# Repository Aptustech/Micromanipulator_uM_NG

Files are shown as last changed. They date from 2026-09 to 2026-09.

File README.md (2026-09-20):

# Micromanipulator_uM_NG

> ⚠️ **Disclaimer:** This is a preliminary hardware design and is currently **untested**. Use or produce these designs at your own risk.

**Micromanipulator_uM_NG** is a next-generation controller system designed for precision micromanipulation. It improves upon previous designs by introducing higher processing power, expanded I/O capabilities, reliable high-speed sensor communication, and comprehensive power monitoring.

## Acknowledgments & Prior Work

This project is the next-generation iteration of the original electronic system for [MicroManipulatorStepper](https://github.com/0x23/MicroManipulatorStepper) by [@0x23](https://github.com/0x23).
---

## Interactive KiCAD Design Viewers

You can inspect the schematics and PCB layouts directly in your browser without opening KiCAD, powered by [KiCanvas](https://kicanvas.org/):

* 🔗 **[View Sensor Board (MT6835 V1.0)](https://kicanvas.org/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)**
* 🔗 **[View Controller Board (uM_Controller V1.0)](https://kicanvas.org/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)**

---

## Key Features & Highlights

* **Powered by RP2350B:** Upgraded to the RP2350B microcontroller to leverage its high IO count and advanced processing capabilities.
* **High-Speed LVDS Link:** Uses Low-Voltage Differential Signaling (LVDS) lines between the main controller and sensor boards, enabling a high-speed, noise-resilient SPI bus operating at **15 MHz**.
* **Power & Diagnostics:**
  * **Input Voltage Monitoring:** Real-time tracking of the main supply voltage.
  * **Per-Motor Current Sensing:** Dedicated current monitoring for each individual motor driver channel.
* **Modular Expansion:** Includes an dedicated extension connector for easily adding custom interfaces, daughterboards, or peripheral modules.

---

## Hardware Repository Structure

```text
├── MT6835/
│   └── V1.0/          # MT6835 encoder/sensor board design files
└── uM_Controller/
    └── V1.0/          # Main RP2350B controller board design files

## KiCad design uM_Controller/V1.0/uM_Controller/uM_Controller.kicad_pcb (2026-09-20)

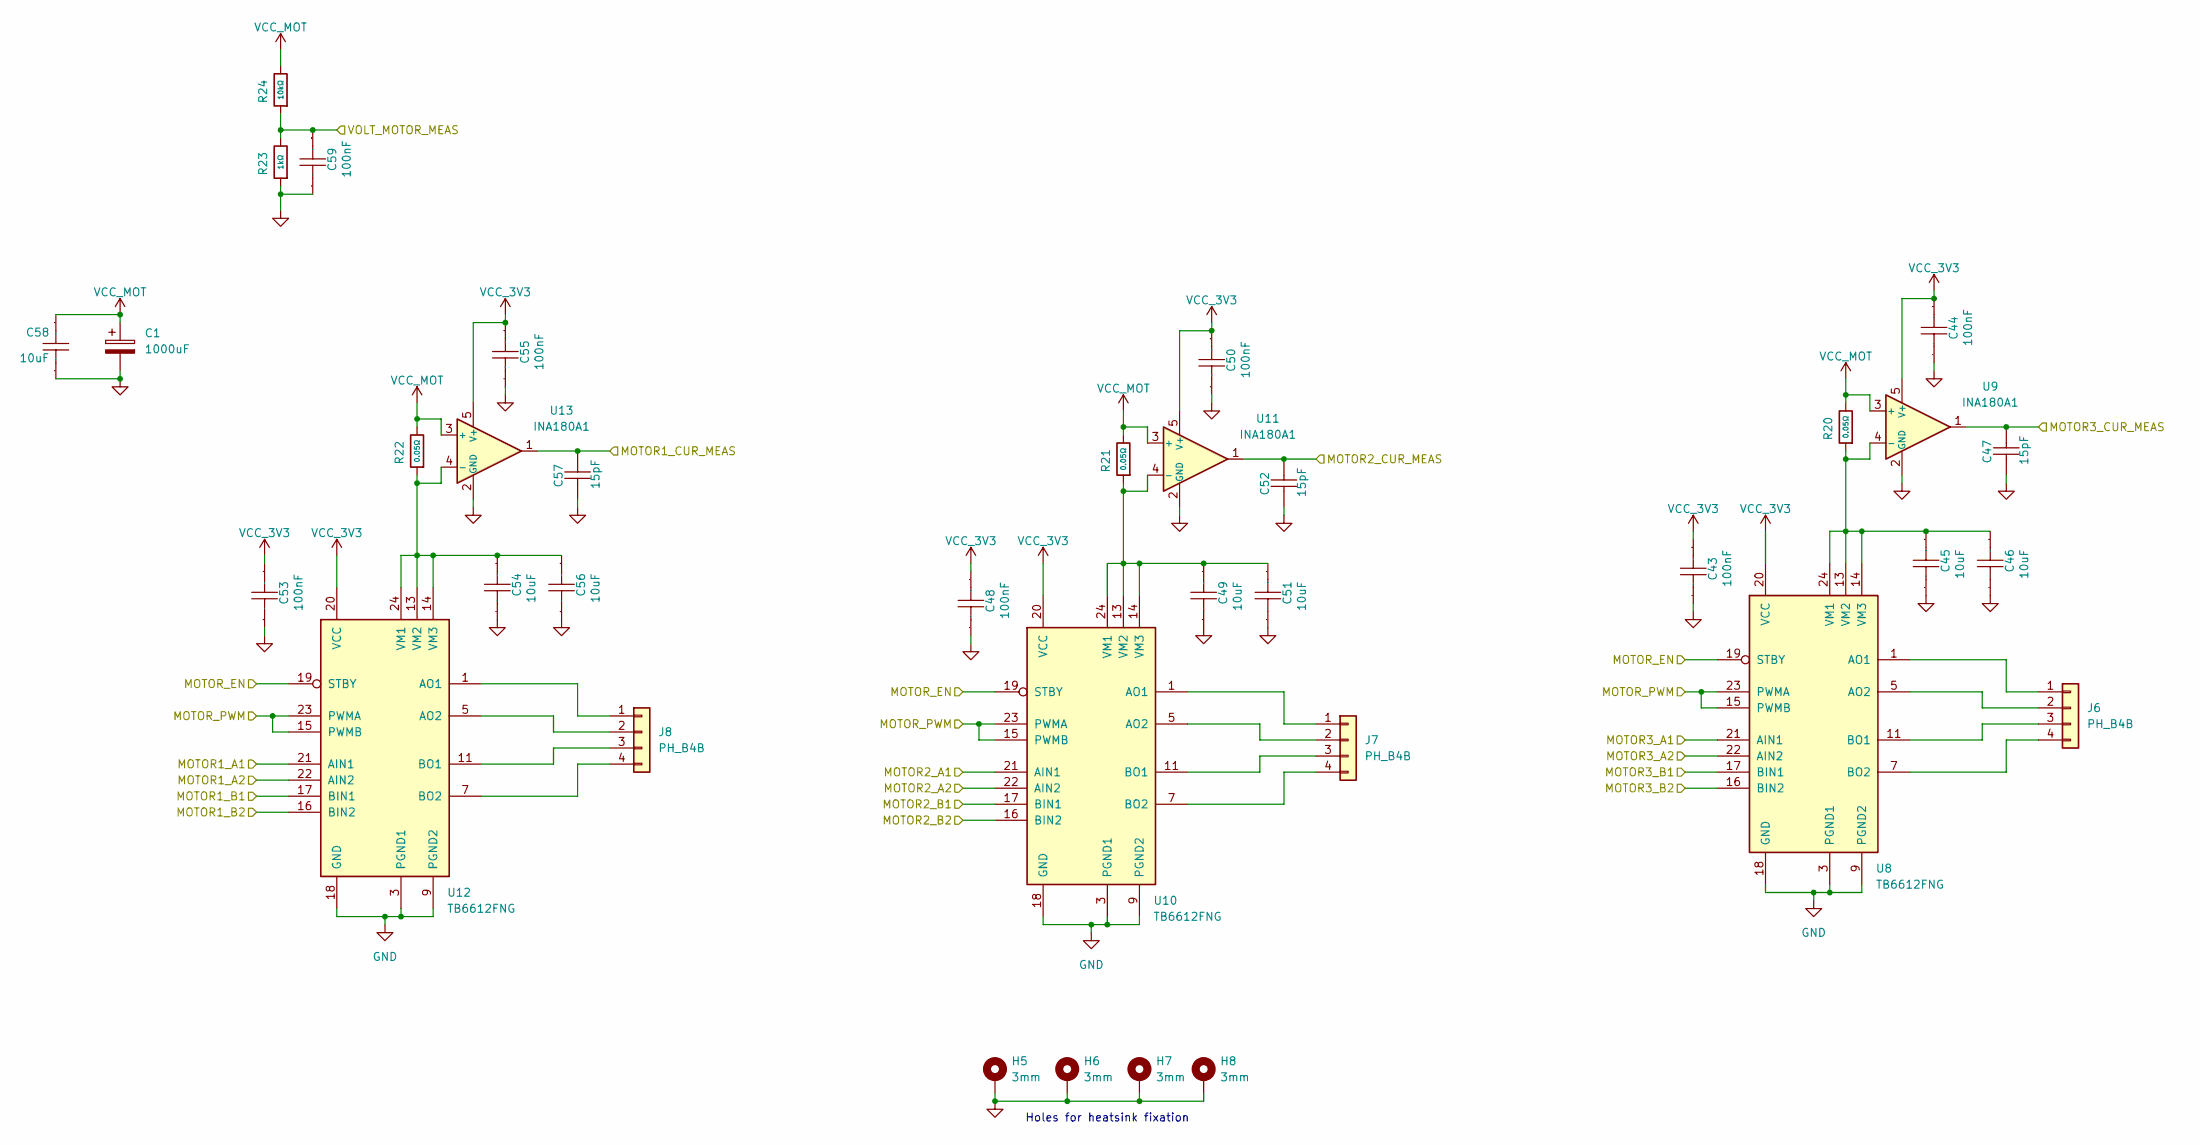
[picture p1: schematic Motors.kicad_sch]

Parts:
C1: 1000uF; CP_Radial_D10.0mm_P5.00mm_P7.50mm; Manufacturer Part 16ZLH1000MEFC10X16; LCSC C338175
C43, C44, C48, C50, C53, C55, C59: 100nF; C_0402_1005Metric; Manufacturer Part CL05B104KO5NNNC; LCSC Part Name 100nF ±10% 16V
C45, C46, C49, C51, C54, C56, C58: 10uF; C_1206_3216Metric; Manufacturer Part CL31A106KBHNNNE; LCSC Part Name 10uF ±10% 50V 1206
C47, C52, C57: 15pF; C_0402_1005Metric; Manufacturer Part 0402CG150J500NT; LCSC Part Name 15pF ±5% 50V
H5, H6, H7, H8: 3mm; MountingHole_3.2mm_M3_ISO14580_Pad_TopBottom
J6, J7, J8: PH_B4B; JST_PH_B4B-PH-K_1x04_P2.00mm_Vertical; Manufacturer Part PH-4A; LCSC C2321
R20, R21, R22: 0.05Ω; R_0805_2012Metric; Overload Voltage (Max) 50V; Tolerance ±1%; Part ERJ-6BWFR050V; LCSC C2075868
R23: 1kΩ; R_0402_1005Metric; Overload Voltage (Max) 50V; Tolerance ±1%; Part 0402WGF1001TCE; LCSC C11702
R24: 10kΩ; R_0402_1005Metric; Overload Voltage (Max) 50V; Tolerance ±1%; Part 0402WGF1002TCE; LCSC C25744
U8, U10, U12: TB6612FNG; SSOP-24_5.3x8.2mm_P0.65mm
U9, U11, U13: INA180A1; SOT-23-5

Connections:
/Motors/MOTOR1_A1: U12.21 (AIN1); also elsewhere on the board
/Motors/MOTOR1_A2: U12.22 (AIN2); also elsewhere on the board
/Motors/MOTOR1_B1: U12.17 (BIN1); also elsewhere on the board
/Motors/MOTOR1_B2: U12.16 (BIN2); also elsewhere on the board
/Motors/MOTOR1_CUR_MEAS: C57.1, U13.1; also elsewhere on the board
/Motors/MOTOR2_A1: U10.21 (AIN1); also elsewhere on the board
/Motors/MOTOR2_A2: U10.22 (AIN2); also elsewhere on the board
/Motors/MOTOR2_B1: U10.17 (BIN1); also elsewhere on the board
/Motors/MOTOR2_B2: U10.16 (BIN2); also elsewhere on the board
/Motors/MOTOR2_CUR_MEAS: C52.1, U11.1; also elsewhere on the board
/Motors/MOTOR3_A1: U8.21 (AIN1); also elsewhere on the board
/Motors/MOTOR3_A2: U8.22 (AIN2); also elsewhere on the board
/Motors/MOTOR3_B1: U8.17 (BIN1); also elsewhere on the board
/Motors/MOTOR3_B2: U8.16 (BIN2); also elsewhere on the board
/Motors/MOTOR3_CUR_MEAS: C47.1, U9.1; also elsewhere on the board
/Motors/MOTOR_EN: U8.19 (STBY), U10.19 (STBY), U12.19 (STBY); also elsewhere on the board
/Motors/MOTOR_PWM: U8.15 (PWMB), U8.23 (PWMA), U10.15 (PWMB), U10.23 (PWMA), U12.15 (PWMB), U12.23 (PWMA); also elsewhere on the board
/Motors/VOLT_MOTOR_MEAS: C59.1, R23.2, R24.1; also elsewhere on the board
GND: C1.2, C43.2, C44.2, C45.2, C46.2, C47.2, C48.2, C49.2, C50.2, C51.2, C52.2, C53.2, C54.2, C55.2, C56.2, C57.2, C58.2, C59.2, H5.1 (1_1), H6.1 (1_1), H7.1 (1_1), H8.1 (1_1), R23.1, U8.3 (PGND1), U8.4 (PGND1), U8.9 (PGND2), U8.10 (PGND2), U8.18 (GND), U9.2 (GND), U10.3 (PGND1), U10.4 (PGND1), U10.9 (PGND2), U10.10 (PGND2), U10.18 (GND), U11.2 (GND), U12.3 (PGND1), U12.4 (PGND1), U12.9 (PGND2), U12.10 (PGND2), U12.18 (GND), U13.2 (GND); also elsewhere on the board
unnamed: J6.1, U8.1 (AO1), U8.2 (AO1)
unnamed: J6.2, U8.5 (AO2), U8.6 (AO2)
unnamed: J6.3, U8.11 (BO1), U8.12 (BO1)
unnamed: J6.4, U8.7 (BO2), U8.8 (BO2)
unnamed: J7.1, U10.1 (AO1), U10.2 (AO1)
unnamed: J7.2, U10.5 (AO2), U10.6 (AO2)
unnamed: J7.3, U10.11 (BO1), U10.12 (BO1)
unnamed: J7.4, U10.7 (BO2), U10.8 (BO2)
unnamed: J8.1, U12.1 (AO1), U12.2 (AO1)
unnamed: J8.2, U12.5 (AO2), U12.6 (AO2)
unnamed: J8.3, U12.11 (BO1), U12.12 (BO1)
unnamed: J8.4, U12.7 (BO2), U12.8 (BO2)
unnamed: C45.1, C46.1, R20.1, U8.13 (VM2), U8.14 (VM3), U8.24 (VM1), U9.4 (-)
unnamed: C49.1, C51.1, R21.1, U10.13 (VM2), U10.14 (VM3), U10.24 (VM1), U11.4 (-)
unnamed: C54.1, C56.1, R22.1, U12.13 (VM2), U12.14 (VM3), U12.24 (VM1), U13.4 (-)
VCC_3V3: C43.1, C44.1, C48.1, C50.1, C53.1, C55.1, U8.20 (VCC), U9.5 (V+), U10.20 (VCC), U11.5 (V+), U12.20 (VCC), U13.5 (V+); also elsewhere on the board
VCC_MOT: C1.1, C58.1, R20.2, R21.2, R22.2, R24.2, U9.3 (+), U11.3 (+), U13.3 (+); also elsewhere on the board

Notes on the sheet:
Holes for heatsink fixation

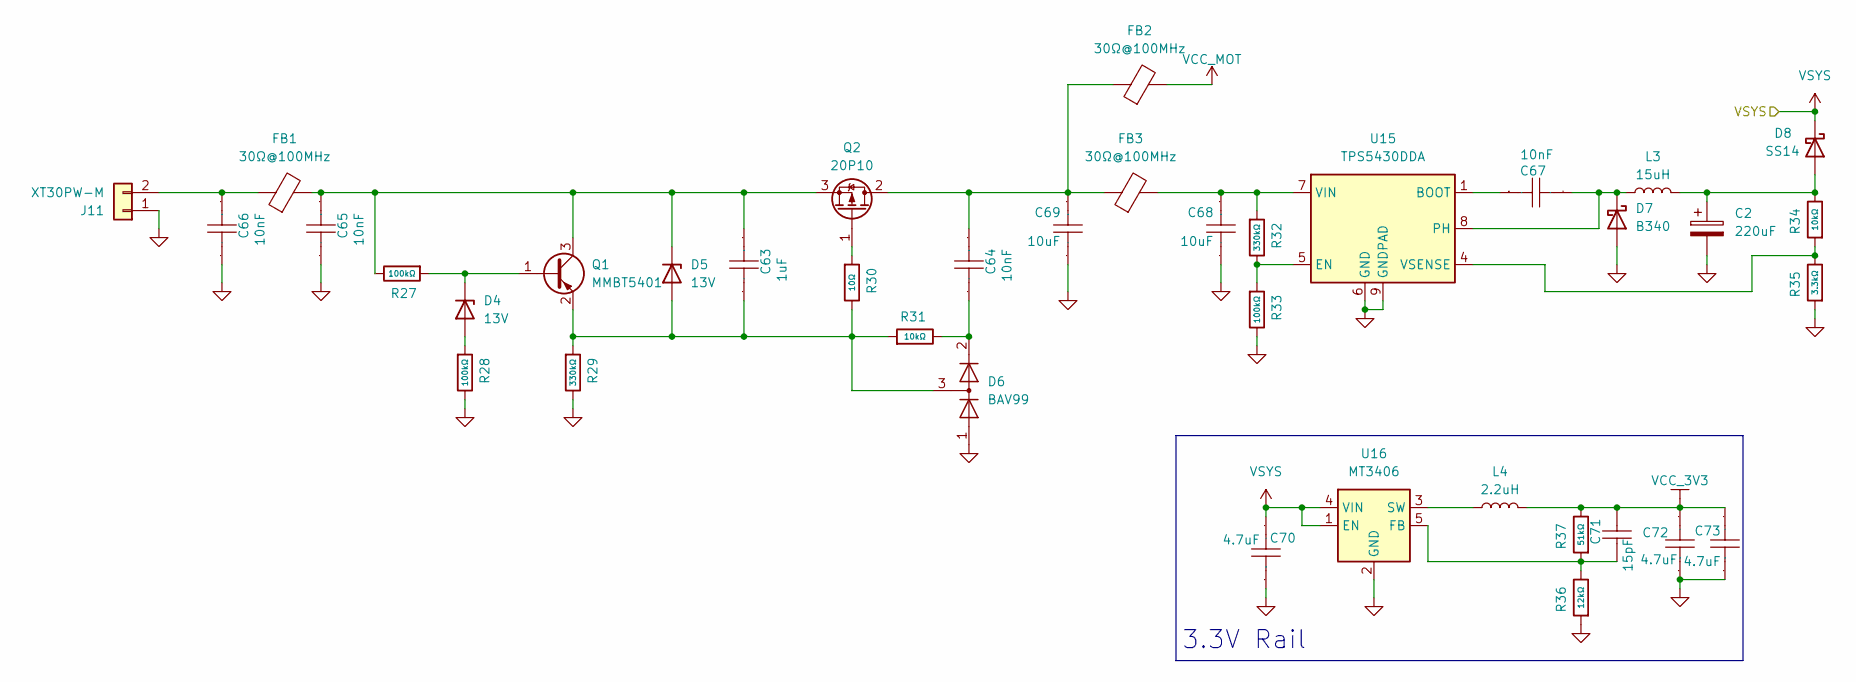
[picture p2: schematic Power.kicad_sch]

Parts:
C2: 220uF; CP_Radial_D6.3mm_P2.50mm; Manufacturer Part ERR1AM221E07OT; LCSC C105293
C63: 1uF; C_0603_1608Metric; Manufacturer Part CL10A105KB8NNNC; LCSC C15849
C64, C65, C66, C67: 10nF; C_0603_1608Metric; Manufacturer Part 0603B103K500NT; LCSC C57112
C68, C69: 10uF; C_1206_3216Metric; Manufacturer Part CL31A106KBHNNNE; LCSC Part Name 10uF ±10% 50V 1206
C70, C72, C73: 4.7uF; C_0402_1005Metric; Manufacturer Part CL05A475MP5NRNC; LCSC Part Name 4.7uF ±20% 10V
C71: 15pF; C_0402_1005Metric; Manufacturer Part 0402CG150J500NT; LCSC Part Name 15pF ±5% 50V
D4, D5: 13V; D_SOD-123; Manufacturer Part BZT52C13; LCSC BZT52C13
D6: BAV99; SOT-23; Manufacturer Part BAV99,215; LCSC C2500
D7: B340; D_SMC; Manufacturer Part B340-13-F-HXY; LCSC C52988714
D8: SS14; D_SMA; Manufacturer Part SS14; LCSC C2480
FB1, FB2, FB3: 30Ω@100MHz; L_0805_2012Metric; Manufacturer Part YI201209A300-10R0T; LCSC C20416195
J11: XT30PW-M; AMASS_XT30PW-M_1x02_P2.50mm_Horizontal
L3: 15uH; L_Taiyo-Yuden_NR-60xx; Manufacturer Part FNR6045S150MT; LCSC C168078
L4: 2.2uH; L_1008_2520Metric; Manufacturer Part FTC252010S2R2MBCA; LCSC C5832358
Q1: MMBT5401; SOT-23; Manufacturer Part MMBT5401(RANGE:200-300); LCSC C8326
Q2: 20P10; TO-252-2; Manufacturer Part 20P10; LCSC C18164396
R27, R28, R33: 100kΩ; R_0603_1608Metric; Overload Voltage (Max) 75V; Tolerance ±1%; Part 0603WAF1003T5E; LCSC C25803
R29, R32: 330kΩ; R_0603_1608Metric; Overload Voltage (Max) 75V; Tolerance ±1%; Part 0603WAF3303T5E; LCSC C23137
R30: 10Ω; R_0603_1608Metric; Overload Voltage (Max) 75V; Tolerance ±1%; Part 0603WAF100JT5E; LCSC C22859
R31: 10kΩ; R_0603_1608Metric; Overload Voltage (Max) 75V; Tolerance ±1%; Part 0603WAF1002T5E; LCSC C25804
R34: 10kΩ; R_0402_1005Metric; Overload Voltage (Max) 50V; Tolerance ±1%; Part 0402WGF1002TCE; LCSC C25744
R35: 3.3kΩ; R_0402_1005Metric; Overload Voltage (Max) 50V; Tolerance ±1%; Part 0402WGF3301TCE; LCSC C25890
R36: 12kΩ; R_0402_1005Metric; Overload Voltage (Max) 50V; Tolerance ±1%; Part 0402WGF1202TCE; LCSC C25752
R37: 51kΩ; R_0402_1005Metric; Overload Voltage (Max) 50V; Tolerance ±1%; Part 0402WGF5102TCE; LCSC C25794
U15: TPS5430DDA; TI_SO-PowerPAD-8_ThermalVias; Manufacturer Part TPS5430DDA; LCSC C9864
U16: MT3406; SOT-23-5; Manufacturer Part MT3406; LCSC C22462728

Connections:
GND: C2.2, C65.2, C66.2, C68.2, C69.2, C70.1, C72.1, C73.1, D6.1 (K), D7.2 (A), J11.1, R28.2, R29.2, R33.2, R35.1, R36.1, U15.6 (GND), U15.9 (GNDPAD), U16.2 (GND); also elsewhere on the board
unnamed: D4.2 (A), R28.1
unnamed: D4.1 (K), Q1.1 (B), R27.1
unnamed: C63.2, D5.2 (A), D6.3 (K), Q1.2 (E), R29.1, R30.2, R31.1
unnamed: C63.1, C65.1, D5.1 (K), FB1.2, Q1.3 (C), Q2.3 (S), R27.2
unnamed: C64.2, D6.2 (A), R31.2
unnamed: C67.2, D7.1 (K), L3.1, U15.8 (PH)
unnamed: C2.1, D8.2 (A), L3.2, R34.2
unnamed: C66.1, FB1.1, J11.2
unnamed: C64.1, C69.1, FB2.1, FB3.1, Q2.2 (D)
unnamed: Q2.1 (G), R30.1
unnamed: C67.1, U15.1 (BOOT)
unnamed: R32.2, R33.1, U15.5 (EN)
unnamed: C68.1, FB3.2, R32.1, U15.7 (VIN)
unnamed: R34.1, R35.2, U15.4 (VSENSE)
unnamed: C71.2, R36.2, R37.1, U16.5 (FB)
unnamed: L4.1, U16.3 (SW)
VCC_3V3: C71.1, C72.2, C73.2, L4.2, R37.2; also elsewhere on the board
VCC_MOT: FB2.2; also elsewhere on the board
VSYS: C70.2, D8.1 (K), U16.1 (EN), U16.4 (VIN); also elsewhere on the board

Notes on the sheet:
3.3V Rail

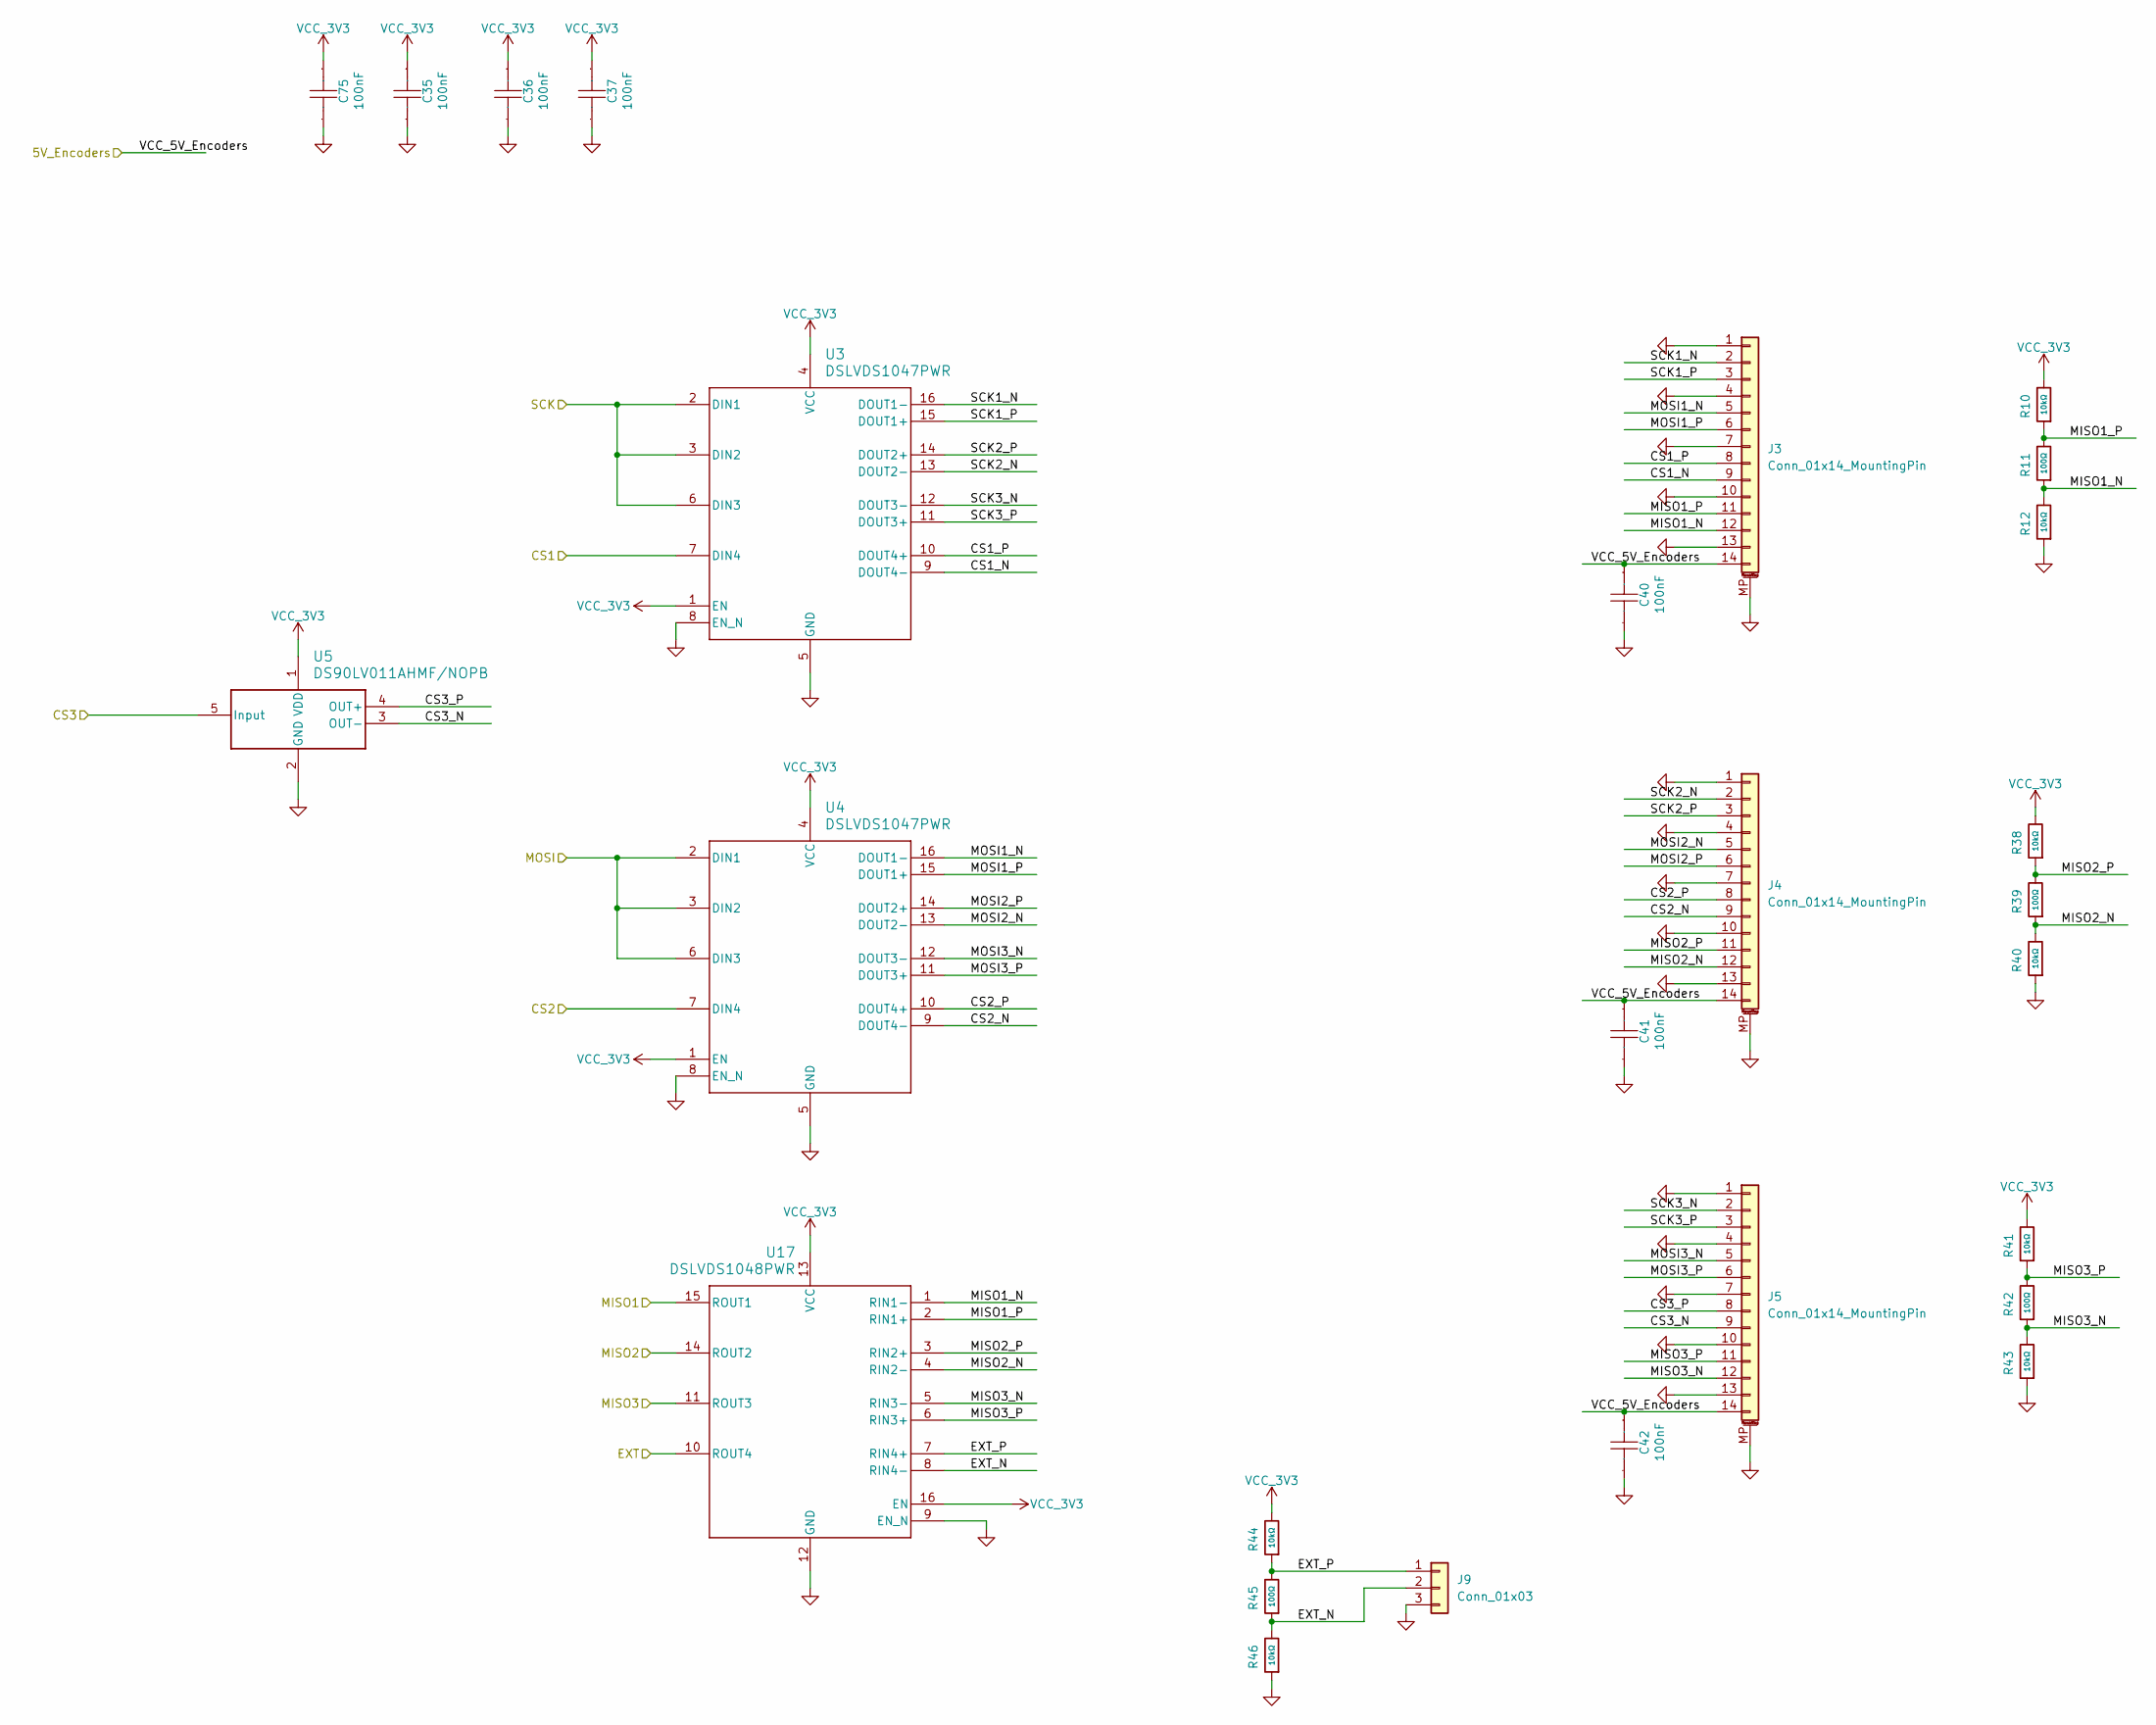
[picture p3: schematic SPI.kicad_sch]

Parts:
C35, C36, C37, C40, C41, C42, C75: 100nF; C_0402_1005Metric; Manufacturer Part CL05B104KO5NNNC; LCSC Part Name 100nF ±10% 16V
J3, J4, J5: Conn_01x14_MountingPin; Amphenol_F32R-1A7x1-11014_1x14-1MP_P0.5mm_Horizontal; Manufacturer Part F32R-1A7H1-11014 / AFC07-S14FCC-00; LCSC C38179
J9: Conn_01x03; PinHeader_1x03_P2.54mm_Vertical
R10, R12, R38, R40, R41, R43, R44, R46: 10kΩ; R_0402_1005Metric; Overload Voltage (Max) 50V; Tolerance ±1%; Part 0402WGF1002TCE; LCSC C25744
R11, R39, R42, R45: 100Ω; R_0402_1005Metric; Overload Voltage (Max) 50V; Tolerance ±1%; Part 0402WGF1000TCE; LCSC C25076
U3, U4: DSLVDS1047PWR; TSSOP-16_4.4x5mm_P0.65mm; Manufacturer Part DSLVDS1047PWR; LCSC C2671205
U5: DS90LV011AHMF/NOPB; SOT-23-5; Manufacturer Part DS90LV011AHMF/NOPB; LCSC C2671548
U17: DSLVDS1048PWR; TSSOP-16_4.4x5mm_P0.65mm; Manufacturer Part DSLVDS1048PWR; LCSC C2671655

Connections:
/RP2350B/CS1: U3.7 (DIN4); also elsewhere on the board
/RP2350B/CS2: U4.7 (DIN4); also elsewhere on the board
/RP2350B/CS3: U5.5 (Input); also elsewhere on the board
/RP2350B/MISO1: U17.15 (ROUT1); also elsewhere on the board
/RP2350B/MISO2: U17.14 (ROUT2); also elsewhere on the board
/RP2350B/MISO3: U17.11 (ROUT3); also elsewhere on the board
/RP2350B/SPI0_MOSI: U4.2 (DIN1), U4.3 (DIN2), U4.6 (DIN3); also elsewhere on the board
/RP2350B/SPI0_SCK: U3.2 (DIN1), U3.3 (DIN2), U3.6 (DIN3); also elsewhere on the board
/SPI_Encoders/CS1_N: J3.9, U3.9 (DOUT4-)
/SPI_Encoders/CS1_P: J3.8, U3.10 (DOUT4+)
/SPI_Encoders/CS2_N: J4.9, U4.9 (DOUT4-)
/SPI_Encoders/CS2_P: J4.8, U4.10 (DOUT4+)
/SPI_Encoders/CS3_N: J5.9, U5.3 (OUT-)
/SPI_Encoders/CS3_P: J5.8, U5.4 (OUT+)
/SPI_Encoders/EXT: U17.10 (ROUT4)
/SPI_Encoders/EXT_N: J9.2, R45.1, R46.2, U17.8 (RIN4-)
/SPI_Encoders/EXT_P: J9.1, R44.1, R45.2, U17.7 (RIN4+)
/SPI_Encoders/MISO1_N: J3.12, R11.1, R12.2, U17.1 (RIN1-)
/SPI_Encoders/MISO1_P: J3.11, R10.1, R11.2, U17.2 (RIN1+)
/SPI_Encoders/MISO2_N: J4.12, R39.1, R40.2, U17.4 (RIN2-)
/SPI_Encoders/MISO2_P: J4.11, R38.1, R39.2, U17.3 (RIN2+)
/SPI_Encoders/MISO3_N: J5.12, R42.1, R43.2, U17.5 (RIN3-)
/SPI_Encoders/MISO3_P: J5.11, R41.1, R42.2, U17.6 (RIN3+)
/SPI_Encoders/MOSI1_N: J3.5, U4.16 (DOUT1-)
/SPI_Encoders/MOSI1_P: J3.6, U4.15 (DOUT1+)
/SPI_Encoders/MOSI2_N: J4.5, U4.13 (DOUT2-)
/SPI_Encoders/MOSI2_P: J4.6, U4.14 (DOUT2+)
/SPI_Encoders/MOSI3_N: J5.5, U4.12 (DOUT3-)
/SPI_Encoders/MOSI3_P: J5.6, U4.11 (DOUT3+)
/SPI_Encoders/SCK1_N: J3.2, U3.16 (DOUT1-)
/SPI_Encoders/SCK1_P: J3.3, U3.15 (DOUT1+)
/SPI_Encoders/SCK2_N: J4.2, U3.13 (DOUT2-)
/SPI_Encoders/SCK2_P: J4.3, U3.14 (DOUT2+)
/SPI_Encoders/SCK3_N: J5.2, U3.12 (DOUT3-)
/SPI_Encoders/SCK3_P: J5.3, U3.11 (DOUT3+)
/SPI_Encoders/VCC_5V_Encoders: C40.1, C41.1, C42.1, J3.14, J4.14, J5.14; also elsewhere on the board
GND: C35.2, C36.2, C37.2, C40.2, C41.2, C42.2, C75.2, J3.1, J3.4, J3.7, J3.10, J3.13, J3.MP (MountPin), J4.1, J4.4, J4.7, J4.10, J4.13, J4.MP (MountPin), J5.1, J5.4, J5.7, J5.10, J5.13, J5.MP (MountPin), J9.3, R12.1, R40.1, R43.1, R46.1, U3.5 (GND), U3.8 (EN_N), U4.5 (GND), U4.8 (EN_N), U5.2 (GND), U17.9 (EN_N), U17.12 (GND); also elsewhere on the board
VCC_3V3: C35.1, C36.1, C37.1, C75.1, R10.2, R38.2, R41.2, R44.2, U3.1 (EN), U3.4 (VCC), U4.1 (EN), U4.4 (VCC), U5.1 (VDD), U17.13 (VCC), U17.16 (EN); also elsewhere on the board

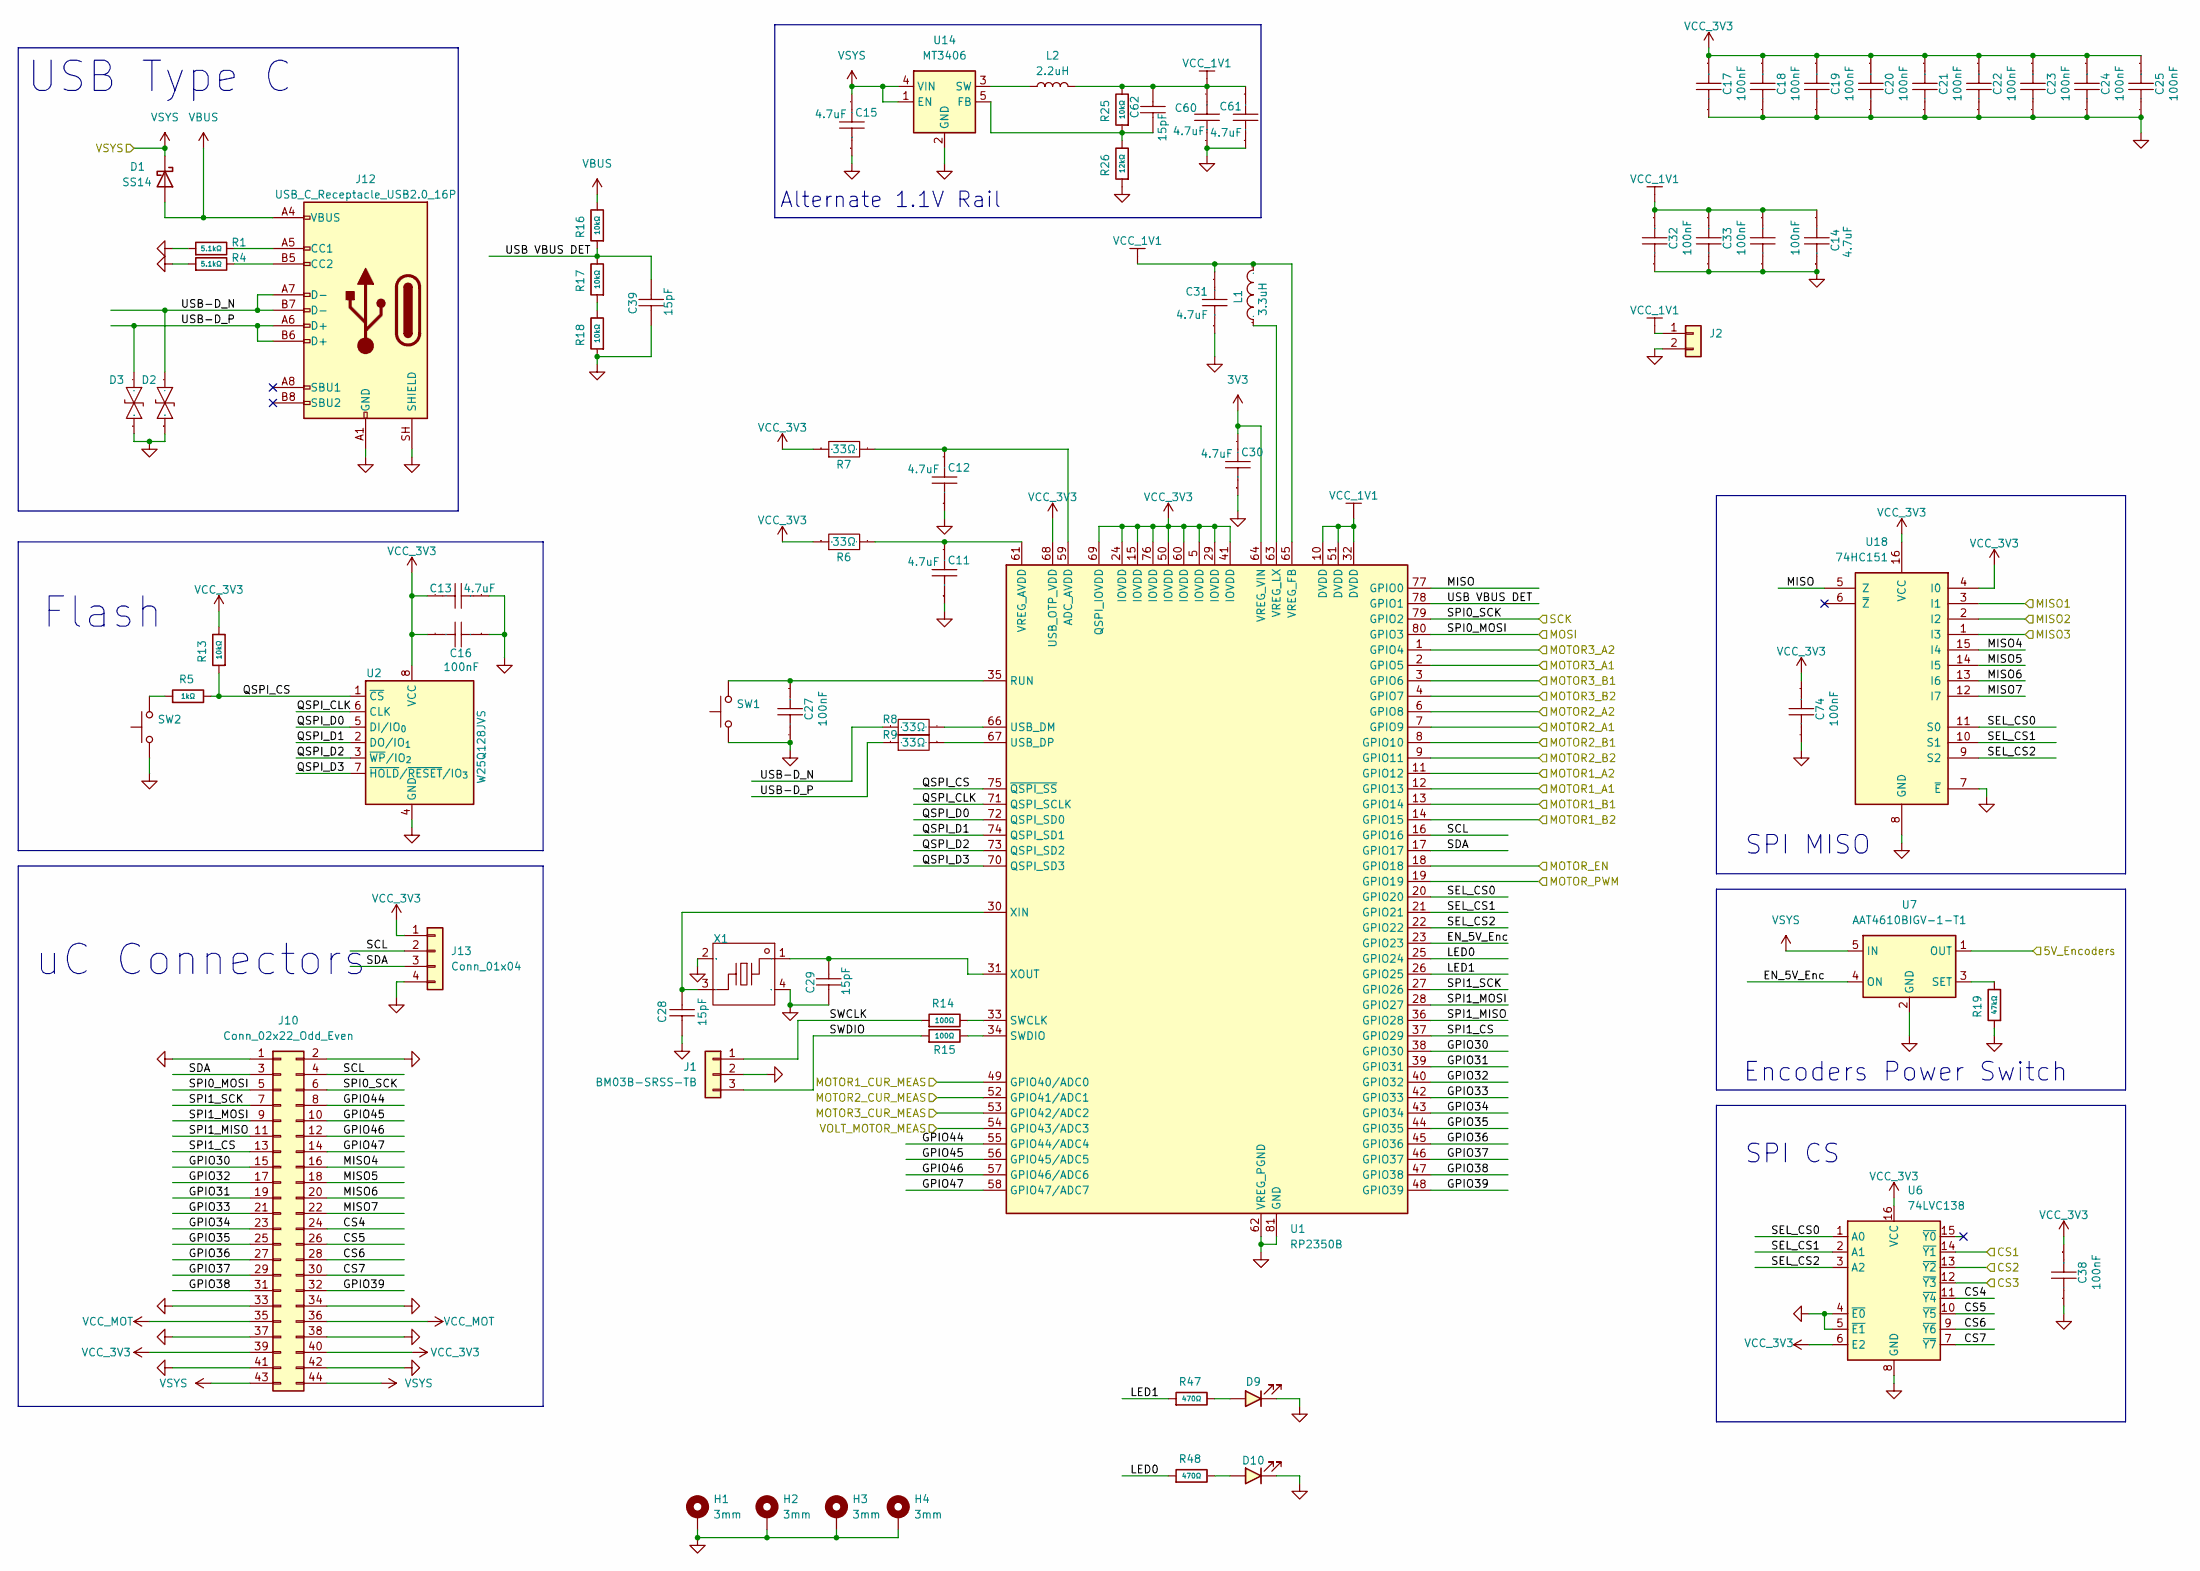
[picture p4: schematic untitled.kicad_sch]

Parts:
C11, C12, C13, C14, C15, C60, C61: 4.7uF; C_0402_1005Metric; Manufacturer Part CL05A475MP5NRNC; LCSC Part Name 4.7uF ±20% 10V
C16, C17, C18, C19, C20, C21, C22, C23, C24, C25, C27, C32, C33, C34, C38, C74: 100nF; C_0402_1005Metric; Manufacturer Part CL05B104KO5NNNC; LCSC Part Name 100nF ±10% 16V
C28, C29, C39, C62: 15pF; C_0402_1005Metric; Manufacturer Part 0402CG150J500NT; LCSC Part Name 15pF ±5% 50V
C30, C31: 4.7uF; C_0603_1608Metric; Manufacturer Part CL10A475KO8NNNC; LCSC Part Name 16V 4.7uF X5R ±10% 0603
D1: SS14; D_SMA; Manufacturer Part SS14; LCSC C2480
D2, D3: RCLAMP0521P.TCT-MS; D_0402_1005Metric; Manufacturer Part RCLAMP0521P.TCT-MS; LCSC Part Name 双向TVS 5V截止 4A峰值脉冲 丝印N
D9: LED; LED_0805_2012Metric; Manufacturer Part KT-0805G; LCSC C2297
D10: LED; LED_0805_2012Metric; Manufacturer Part NCD0805R1; LCSC C84256
H1, H2, H3, H4: 3mm; MountingHole_3.2mm_M3_ISO14580_Pad_TopBottom
J1: BM03B-SRSS-TB; JST_SH_BM03B-SRSS-TB_1x03-1MP_P1.00mm_Vertical; Manufacturer Part BM03B-SRSS-TB; LCSC C160389
J2: Conn_01x02; PinHeader_1x02_P2.54mm_Vertical
J10: Conn_02x22_Odd_Even; PinHeader_2x22_P2.54mm_Vertical
J12: USB_C_Receptacle_USB2.0_16P; USB_C_Receptacle_GCT_USB4105-xx-A_16P_TopMnt_Horizontal; Manufacturer Part USB4105-GF-A-120; LCSC C5184243
J13: Conn_01x04; PinHeader_1x04_P2.54mm_Vertical
L1: L_Changjiang_FTC201610D; Manufacturer Part AOTA-B201610S3R3-101-T; LCSC Part Name AOTA-B201610S3R3-101-T
L2: 2.2uH; L_1008_2520Metric; Manufacturer Part FTC252010S2R2MBCA; LCSC C5832358
R1, R4: 5.1kΩ; R_0402_1005Metric; Overload Voltage (Max) 50V; Tolerance ±1%; Part 0402WGF5101TCE; LCSC C25905
R5: 1kΩ; R_0402_1005Metric; Overload Voltage (Max) 50V; Tolerance ±1%; Part 0402WGF1001TCE; LCSC C11702
R6, R7, R8, R9: 33Ω; R_0402_1005Metric; Manufacturer Part 0402WGF330JTCE; LCSC Part Name 33Ω ±1% 62.5mW 厚膜电阻
R13, R16, R17, R18, R25: 10kΩ; R_0402_1005Metric; Overload Voltage (Max) 50V; Tolerance ±1%; Part 0402WGF1002TCE; LCSC C25744
R14, R15: 100Ω; R_0402_1005Metric; Overload Voltage (Max) 50V; Tolerance ±1%; Part 0402WGF1000TCE; LCSC C25076
R19: 47kΩ; R_0402_1005Metric; Overload Voltage (Max) 50V; Tolerance ±1%; Part 0402WGF4702TCE; LCSC C25792
R26: 12kΩ; R_0402_1005Metric; Overload Voltage (Max) 50V; Tolerance ±1%; Part 0402WGF1202TCE; LCSC C25752
R47, R48: 470Ω; R_0402_1005Metric; Overload Voltage (Max) 50V; Tolerance ±1%; Part 0402WGF4700TCE; LCSC C25117
SW1, SW2: K2-1808SN-A4SW-01; SW_Push_1P1T_XKB_TS-1187A; Manufacturer Part TS-1187A-B-A-B; LCSC C318884
U1: RP2350B; QFN-80-1EP_10x10mm_P0.4mm_EP3.4x3.4mm
U2: W25Q128JVS; SOIC-8_5.3x5.3mm_P1.27mm
U6: 74LVC138; TSSOP-16_4.4x5mm_P0.65mm; Manufacturer Part AiP74LVC138TA16.TB; LCSC C5361835
U7: AAT4610BIGV-1-T1; SOT-23-5; Manufacturer Part RY2121; LCSC C2887853
U14: MT3406; SOT-23-5; Manufacturer Part MT3406; LCSC C22462728
U18: 74HC151; TSSOP-16_4.4x5mm_P0.65mm; Manufacturer Part MC74HC151ADTR2G; LCSC C152523
X1: Crystal_SMD_3225-4Pin_3.2x2.5mm; Manufacturer Part YXC Crystal Oscillators; LCSC C9002

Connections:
3V3: C30.2, U1.64 (VREG_VIN)
/Motors/MOTOR1_A1: U1.12 (GPIO13); also elsewhere on the board
/Motors/MOTOR1_A2: U1.11 (GPIO12); also elsewhere on the board
/Motors/MOTOR1_B1: U1.13 (GPIO14); also elsewhere on the board
/Motors/MOTOR1_B2: U1.14 (GPIO15); also elsewhere on the board
/Motors/MOTOR1_CUR_MEAS: U1.49 (GPIO40/ADC0); also elsewhere on the board
/Motors/MOTOR2_A1: U1.7 (GPIO9); also elsewhere on the board
/Motors/MOTOR2_A2: U1.6 (GPIO8); also elsewhere on the board
/Motors/MOTOR2_B1: U1.8 (GPIO10); also elsewhere on the board
/Motors/MOTOR2_B2: U1.9 (GPIO11); also elsewhere on the board
/Motors/MOTOR2_CUR_MEAS: U1.52 (GPIO41/ADC1); also elsewhere on the board
/Motors/MOTOR3_A1: U1.2 (GPIO5); also elsewhere on the board
/Motors/MOTOR3_A2: U1.1 (GPIO4); also elsewhere on the board
/Motors/MOTOR3_B1: U1.3 (GPIO6); also elsewhere on the board
/Motors/MOTOR3_B2: U1.4 (GPIO7); also elsewhere on the board
/Motors/MOTOR3_CUR_MEAS: U1.53 (GPIO42/ADC2); also elsewhere on the board
/Motors/MOTOR_EN: U1.18 (GPIO18); also elsewhere on the board
/Motors/MOTOR_PWM: U1.19 (GPIO19); also elsewhere on the board
/Motors/VOLT_MOTOR_MEAS: U1.54 (GPIO43/ADC3); also elsewhere on the board
/RP2350B/CS1: U6.14 (~Y1); also elsewhere on the board
/RP2350B/CS2: U6.13 (~Y2); also elsewhere on the board
/RP2350B/CS3: U6.12 (~Y3); also elsewhere on the board
/RP2350B/CS4: J10.24, U6.11 (~Y4)
/RP2350B/CS5: J10.26, U6.10 (~Y5)
/RP2350B/CS6: J10.28, U6.9 (~Y6)
/RP2350B/CS7: J10.30, U6.7 (~Y7)
/RP2350B/EN_5V_Enc: U1.23 (GPIO23), U7.4 (ON)
/RP2350B/GPIO30: J10.15, U1.38 (GPIO30)
/RP2350B/GPIO31: J10.19, U1.39 (GPIO31)
/RP2350B/GPIO32: J10.17, U1.40 (GPIO32)
/RP2350B/GPIO33: J10.21, U1.42 (GPIO33)
/RP2350B/GPIO34: J10.23, U1.43 (GPIO34)
/RP2350B/GPIO35: J10.25, U1.44 (GPIO35)
/RP2350B/GPIO36: J10.27, U1.45 (GPIO36)
/RP2350B/GPIO37: J10.29, U1.46 (GPIO37)
/RP2350B/GPIO38: J10.31, U1.47 (GPIO38)
/RP2350B/GPIO39: J10.32, U1.48 (GPIO39)
/RP2350B/GPIO44: J10.8, U1.55 (GPIO44/ADC4)
/RP2350B/GPIO45: J10.10, U1.56 (GPIO45/ADC5)
/RP2350B/GPIO46: J10.12, U1.57 (GPIO46/ADC6)
/RP2350B/GPIO47: J10.14, U1.58 (GPIO47/ADC7)
/RP2350B/LED0: R48.1, U1.25 (GPIO24)
/RP2350B/LED1: R47.1, U1.26 (GPIO25)
/RP2350B/MISO: U1.77 (GPIO0), U18.5 (Z)
/RP2350B/MISO1: U18.3 (I1); also elsewhere on the board
/RP2350B/MISO2: U18.2 (I2); also elsewhere on the board
/RP2350B/MISO3: U18.1 (I3); also elsewhere on the board
/RP2350B/MISO4: J10.16, U18.15 (I4)
/RP2350B/MISO5: J10.18, U18.14 (I5)
/RP2350B/MISO6: J10.20, U18.13 (I6)
/RP2350B/MISO7: J10.22, U18.12 (I7)
/RP2350B/QSPI_CLK: U1.71 (QSPI_SCLK), U2.6 (CLK)
/RP2350B/QSPI_CS: R5.2, R13.1, U1.75 (~QSPI_SS), U2.1 (~CS)
/RP2350B/QSPI_D0: U1.72 (QSPI_SD0), U2.5 (DI/IO_{0})
/RP2350B/QSPI_D1: U1.74 (QSPI_SD1), U2.2 (DO/IO_{1})
/RP2350B/QSPI_D2: U1.73 (QSPI_SD2), U2.3 (~WP/IO_{2})
/RP2350B/QSPI_D3: U1.70 (QSPI_SD3), U2.7 (~HOLD/~RESET/IO_{3})
/RP2350B/SCL: J10.4, J13.2, U1.16 (GPIO16)
/RP2350B/SDA: J10.3, J13.3, U1.17 (GPIO17)
/RP2350B/SEL_CS0: U1.20 (GPIO20), U6.1 (A0), U18.11 (S0)
/RP2350B/SEL_CS1: U1.21 (GPIO21), U6.2 (A1), U18.10 (S1)
/RP2350B/SEL_CS2: U1.22 (GPIO22), U6.3 (A2), U18.9 (S2)
/RP2350B/SPI0_MOSI: J10.5, U1.80 (GPIO3); also elsewhere on the board
/RP2350B/SPI0_SCK: J10.6, U1.79 (GPIO2); also elsewhere on the board
/RP2350B/SPI1_CS: J10.13, U1.37 (GPIO29)
/RP2350B/SPI1_MISO: J10.11, U1.36 (GPIO28)
/RP2350B/SPI1_MOSI: J10.9, U1.28 (GPIO27)
/RP2350B/SPI1_SCK: J10.7, U1.27 (GPIO26)
/RP2350B/SWCLK: J1.1, R14.1
/RP2350B/SWDIO: J1.3, R15.1
/RP2350B/USB VBUS DET: C39.1, R16.1, R17.2, U1.78 (GPIO1)
/RP2350B/USB-D_N: D2.2, J12.A7 (D-), J12.B7 (D-), R8.1
/RP2350B/USB-D_P: D3.2, J12.A6 (D+), J12.B6 (D+), R9.1
/SPI_Encoders/VCC_5V_Encoders: U7.1 (OUT); also elsewhere on the board
GND: C11.1, C12.1, C13.1, C14.1, C15.1, C16.1, C17.2, C18.2, C19.2, C20.2, C21.2, C22.2, C23.2, C24.2, C25.2, C27.2, C28.2, C29.2, C30.1, C31.1, C32.2, C33.2, C34.2, C38.2, C39.2, C60.1, C61.1, C74.2, D2.1, D3.1, D9.1 (K), D10.1 (K), H1.1 (1_1), H2.1 (1_1), H3.1 (1_1), H4.1 (1_1), J1.2, J2.2, J10.1, J10.2, J10.33, J10.34, J10.37, J10.38, J10.41, J10.42, J12.A1 (GND), J12.A12 (GND), J12.B1 (GND), J12.B12 (GND), J12.SH (SHIELD), J13.4, R1.1, R4.1, R18.1, R19.1, R26.1, SW1.1, SW2.1, U1.62 (VREG_PGND), U1.81 (GND), U2.4 (GND), U6.4 (~E0), U6.5 (~E1), U6.8 (GND), U7.2 (GND), U14.2 (GND), U18.7 (~E), U18.8 (GND), X1.2 (GND), X1.4 (GND); also elsewhere on the board
unnamed: D9.2 (A), R47.2
unnamed: D10.2 (A), R48.2
unnamed: J12.A5 (CC1), R1.2
unnamed: J12.B5 (CC2), R4.2
unnamed: R5.1, SW2.2
unnamed: R17.1, R18.2
unnamed: C12.2, R7.2, U1.59 (ADC_AVDD)
unnamed: C27.1, SW1.2, U1.35 (RUN)
unnamed: R14.2, U1.33 (SWCLK)
unnamed: R15.2, U1.34 (SWDIO)
unnamed: R8.2, U1.66 (USB_DM)
unnamed: R9.2, U1.67 (USB_DP)
unnamed: C11.2, R6.2, U1.61 (VREG_AVDD)
unnamed: L1.1, U1.63 (VREG_LX)
unnamed: C28.1, U1.30 (XIN), X1.3
unnamed: C29.1, U1.31 (XOUT), X1.1
unnamed: R19.2, U7.3 (SET)
unnamed: C62.2, R25.1, R26.2, U14.5 (FB)
unnamed: L2.1, U14.3 (SW)
VBUS: D1.2 (A), J12.A4 (VBUS), J12.A9 (VBUS), J12.B4 (VBUS), J12.B9 (VBUS), R16.2
VCC_1V1: C14.2, C31.2, C32.1, C33.1, C34.1, C60.2, C61.2, C62.1, J2.1, L1.2, L2.2, R25.2, U1.10 (DVDD), U1.32 (DVDD), U1.51 (DVDD), U1.65 (VREG_FB)
VCC_3V3: C13.2, C16.2, C17.1, C18.1, C19.1, C20.1, C21.1, C22.1, C23.1, C24.1, C25.1, C38.1, C74.1, J10.39, J10.40, J13.1, R6.1, R7.1, R13.2, U1.5 (IOVDD), U1.15 (IOVDD), U1.24 (IOVDD), U1.29 (IOVDD), U1.41 (IOVDD), U1.50 (IOVDD), U1.60 (IOVDD), U1.68 (USB_OTP_VDD), U1.69 (QSPI_IOVDD), U1.76 (IOVDD), U2.8 (VCC), U6.6 (E2), U6.16 (VCC), U18.4 (I0), U18.16 (VCC); also elsewhere on the board
VCC_MOT: J10.35, J10.36; also elsewhere on the board
VSYS: C15.2, D1.1 (K), J10.43, J10.44, U7.5 (IN), U14.1 (EN), U14.4 (VIN); also elsewhere on the board

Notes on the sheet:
Flash
SPI MISO
USB Type C
Encoders Power Switch
uC Connectors
SPI CS
Alternate 1.1V Rail

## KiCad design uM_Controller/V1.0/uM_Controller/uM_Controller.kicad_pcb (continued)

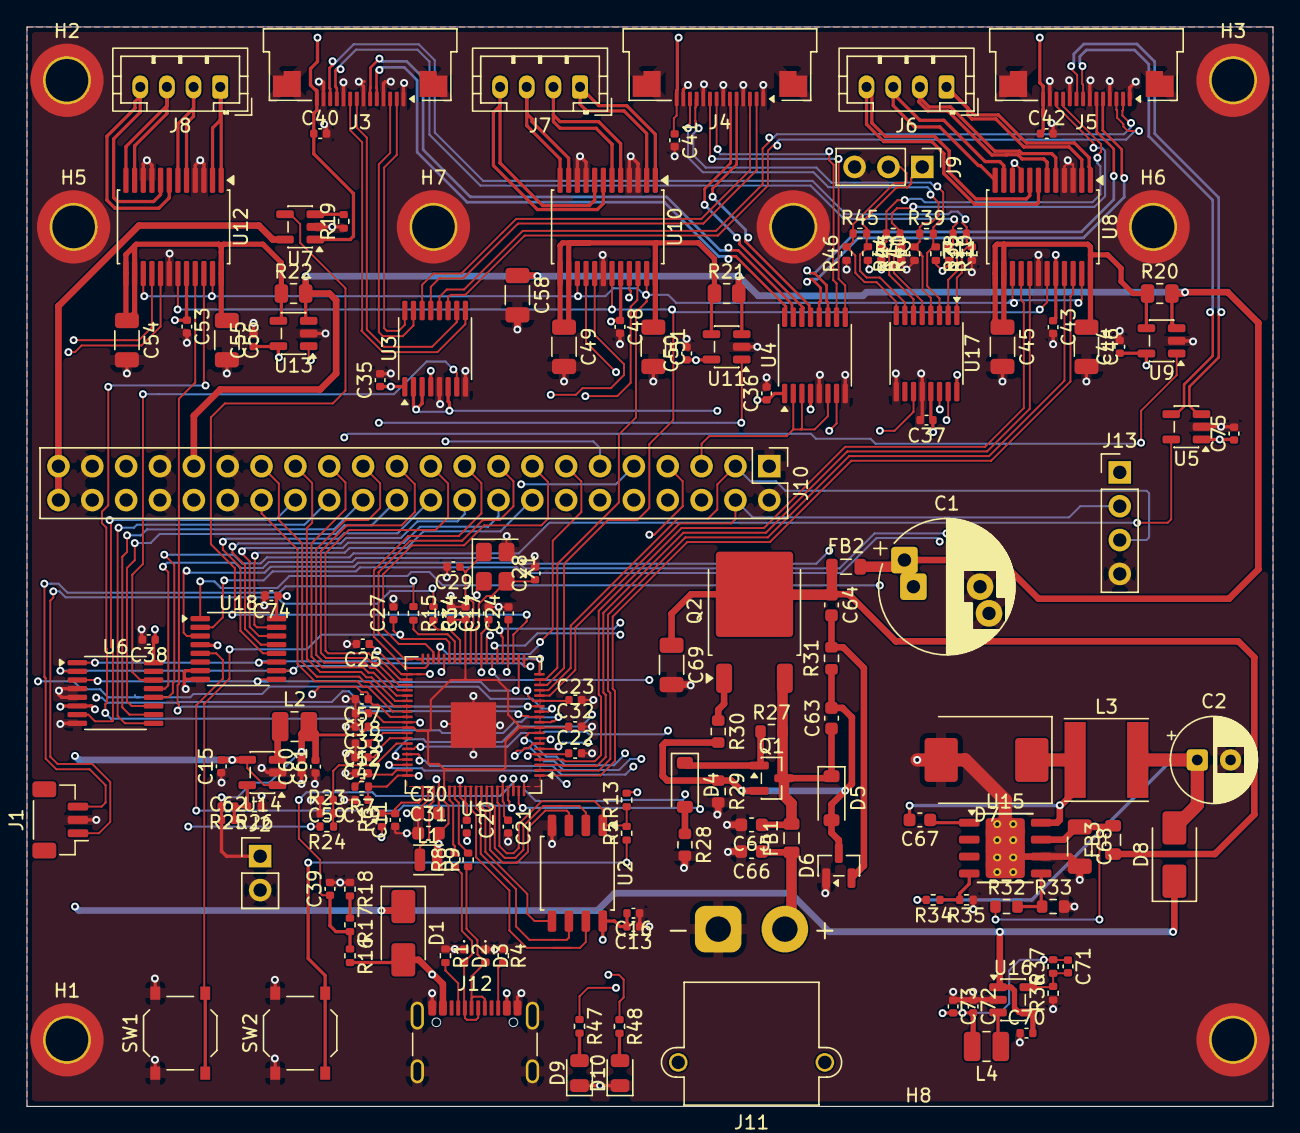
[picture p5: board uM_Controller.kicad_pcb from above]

Board: 4 copper layers, 93.5 x 81.0 mm, 173 parts (0 on the bottom side), 156 nets.

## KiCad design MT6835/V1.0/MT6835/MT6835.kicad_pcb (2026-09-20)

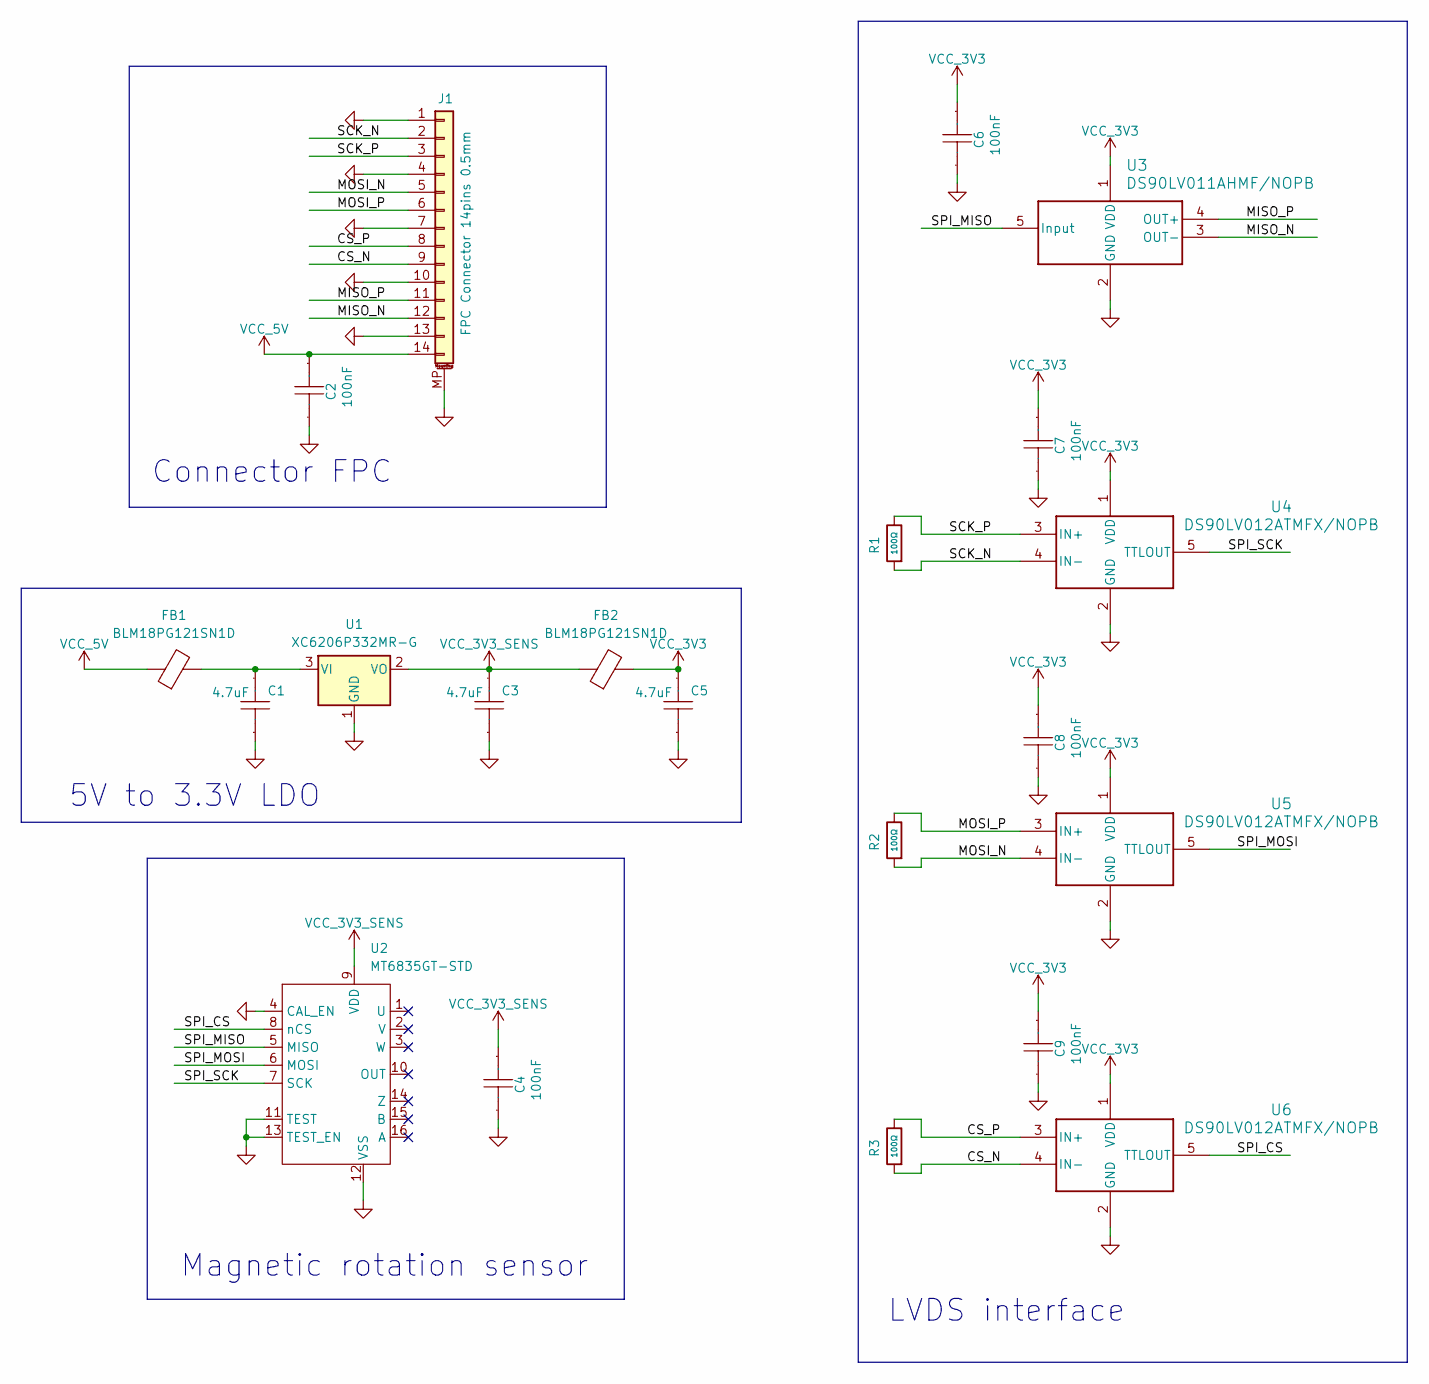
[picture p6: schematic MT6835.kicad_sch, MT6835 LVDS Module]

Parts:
C1, C3, C5: 4.7uF; C_0402_1005Metric; Manufacturer Part CL05A475MP5NRNC; LCSC Part Name 4.7uF ±20% 10V
C2, C4, C6, C7, C8, C9: 100nF; C_0402_1005Metric; Manufacturer Part CL05B104KO5NNNC; LCSC Part Name 100nF ±10% 16V
FB1, FB2: BLM18PG121SN1D; L_0603_1608Metric; Manufacturer Part BLM18PG121SN1D; LCSC C14709
J1: FPC Connector 14pins 0.5mm; Amphenol_F32R-1A7x1-11014_1x14-1MP_P0.5mm_Horizontal; Manufacturer Part F32R-1A7H1-11014 / AFC07-S14FCC-00; LCSC C38179
R1, R2, R3: 100Ω; R_0402_1005Metric; Overload Voltage (Max) 50V; Tolerance ±1%; Part 0402WGF1000TCE; LCSC C25076
U1: XC6206P332MR-G; SOT-23-3; Manufacturer Part XC6206P332MR-G; LCSC C5446
U2: MT6835GT-STD; TSSOP-16_4.4x5mm_P0.65mm; Manufacturer Part MT6835GT-STD-R; LCSC C2932578
U3: DS90LV011AHMF/NOPB; SOT-23-5; Manufacturer Part DS90LV011AHMF/NOPB; LCSC C2671548
U4, U5, U6: DS90LV012ATMFX/NOPB; SOT-23-5

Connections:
/CS_N: J1.9, R3.1, U6.4 (IN-)
/CS_P: J1.8, R3.2, U6.3 (IN+)
/MISO_N: J1.12, U3.3 (OUT-)
/MISO_P: J1.11, U3.4 (OUT+)
/MOSI_N: J1.5, R2.1, U5.4 (IN-)
/MOSI_P: J1.6, R2.2, U5.3 (IN+)
/SCK_N: J1.2, R1.1, U4.4 (IN-)
/SCK_P: J1.3, R1.2, U4.3 (IN+)
/SPI_CS: U2.8 (nCS), U6.5 (TTLOUT)
/SPI_MISO: U2.5 (MISO), U3.5 (Input)
/SPI_MOSI: U2.6 (MOSI), U5.5 (TTLOUT)
/SPI_SCK: U2.7 (SCK), U4.5 (TTLOUT)
GND: C1.1, C2.2, C3.1, C4.2, C5.1, C6.2, C7.2, C8.2, C9.2, J1.1, J1.4, J1.7, J1.10, J1.13, J1.MP (MountPin), U1.1 (GND), U2.4 (CAL_EN), U2.11 (TEST), U2.12 (VSS), U2.13 (TEST_EN), U3.2 (GND), U4.2 (GND), U5.2 (GND), U6.2 (GND)
unnamed: C1.2, FB1.2, U1.3 (VI)
VCC_3V3: C5.2, C6.1, C7.1, C8.1, C9.1, FB2.2, U3.1 (VDD), U4.1 (VDD), U5.1 (VDD), U6.1 (VDD)
VCC_3V3_SENS: C3.2, C4.1, FB2.1, U1.2 (VO), U2.9 (VDD)
VCC_5V: C2.1, FB1.1, J1.14

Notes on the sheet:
5V to 3.3V LDO
Magnetic rotation sensor
Connector FPC
LVDS interface

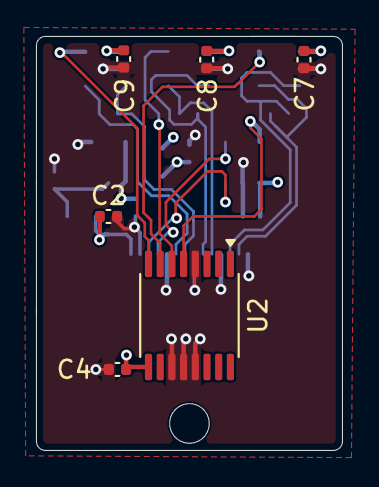
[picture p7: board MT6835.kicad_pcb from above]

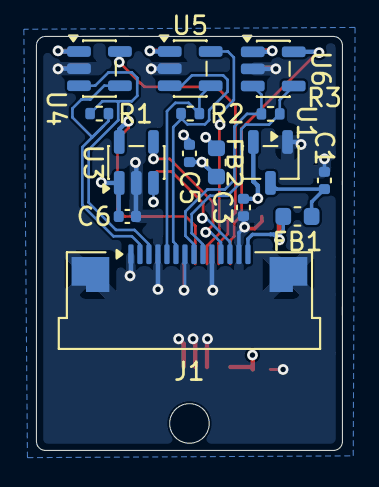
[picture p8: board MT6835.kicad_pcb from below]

Board: 4 copper layers, 17.0 x 23.0 mm, 21 parts (15 on the bottom side), 17 nets.
